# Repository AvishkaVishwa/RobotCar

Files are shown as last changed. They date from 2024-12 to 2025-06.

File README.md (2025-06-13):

# 🤖 Sumo Robot – ESP32 Upgrade Edition

> ⚡ A complete redesign and performance upgrade of my original ESP32-based 2-wheel robot — now featuring 4-wheel differential drive, dual motor drivers, enhanced sensing, and a **custom-designed 2-layer PCB** for clean, robust competition performance.

---
## 🏅 Awards & Achievements

> 🥈 **2nd Place – University Robotics Competition**  
> My previous 2-wheel ESP32-based robot won **2nd place** in a university competition.  
> 🎯 **Challenge Objective:** Remove the maximum number of boxes from a designated area as fast as possible.  
> 💡 The robot autonomously navigated, detected, and pushed objects while avoiding boundaries.  
>
> This new 4-wheel version builds on that success with:
> - A custom PCB for higher stability and motor control
> - Dual-mode (Autonomous + BLE Manual) operation
> - Improved PD-based line tracking and obstacle avoidance
> - Real-time scanning with servo-driven sensors

## 🔄 Evolution of the Project

| Original Prototype | 🚀 **Upgraded Version** |
|---|---|
| ESP32 on protoboard | ESP32 DevKit (38-pin) on custom 2-layer PCB |
| 2-wheel drive with single TB6612FNG  | 4-wheel drive using dual TB6612FNG drivers |
| Breadboard wiring | Professionally routed and labeled PCB in KiCad |
| 1 ultrasonic + 2 IR sensors | 2 ultrasonic + 3 IR sensors |
| Basic C firmware | Modular, RTOS-based firmware with **ESP-IDF** |

### 🔧 The Current design 

| Old Design |
|------------|
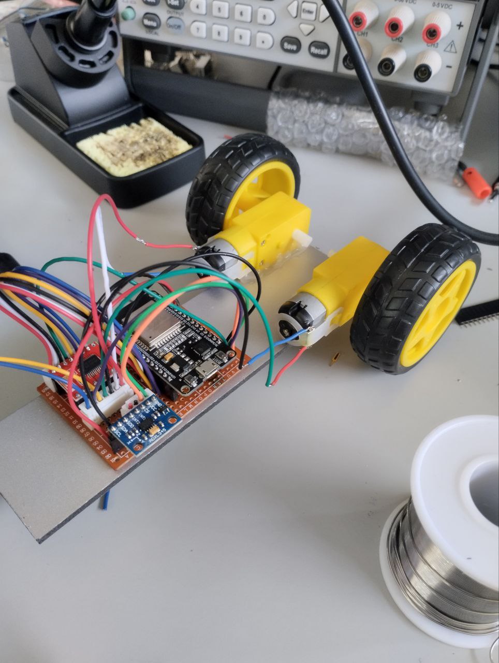
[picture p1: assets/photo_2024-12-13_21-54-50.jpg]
 
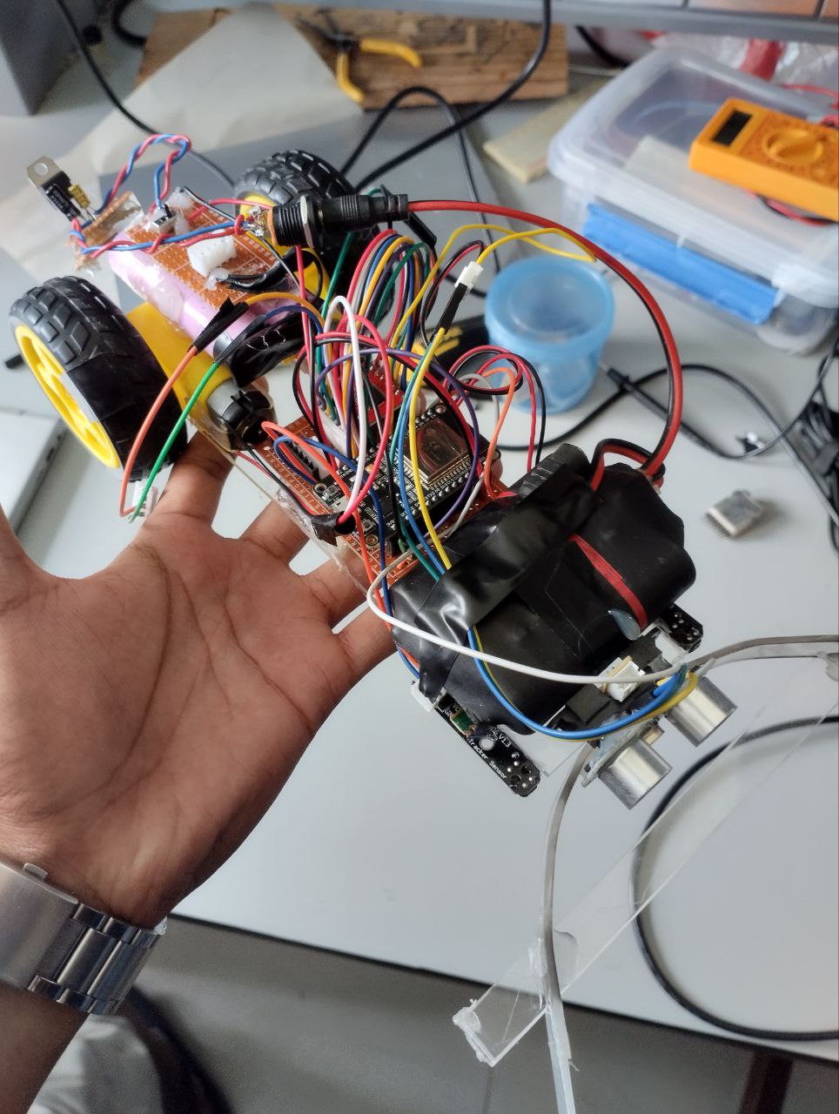
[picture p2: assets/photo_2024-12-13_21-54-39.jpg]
   

---

## ⚙ Hardware Overview

### 📍 ESP32 GPIO Mapping

| Feature | GPIOs | Description |
|---|---|---|
| **Motor Driver 1**  | AIN1: 13, AIN2: 14 | Left Front Motor Direction |
| | BIN1: 12, BIN2: 27 | Left Rear Motor Direction |
| | PWMA: 26, PWMB: 25 | Speed Control (PWM) |
| **Motor Driver 2**  | AIN1: 33, AIN2: 32 | Right Front Motor Direction |
| | BIN1: 19, BIN2: 18 | Right Rear Motor Direction |
| | PWMA: 23, PWMB: 22 | Speed Control (PWM) |
| **STBY Pin** | 15 | Keep HIGH to enable motors |
| **IR Sensors** | 34, 35, 39 | Left, Center, Right (input only) |
| **Ultrasonic** | TRIG1: 5, ECHO1: 36 | Front sensor |
| | TRIG2: 4, ECHO2: 21 | Side sensor |
| **Servos** | SERVO1: 2, SERVO2: 17 | Optional (PWM outputs) |

---

## 📐 PCB Design (KiCad)

This upgrade features a fully custom 2-layer PCB:
- Dual motor driver breakout with decoupling capacitors
- LM2596 buck converter (12V to 5V)
- Pull-up/pull-down resistors for boot-safe ESP32 pins
- Clear silk labels for servo, IR, ultrasonic, and power pins

### PCB Gallery

#### 📘 Schematic View
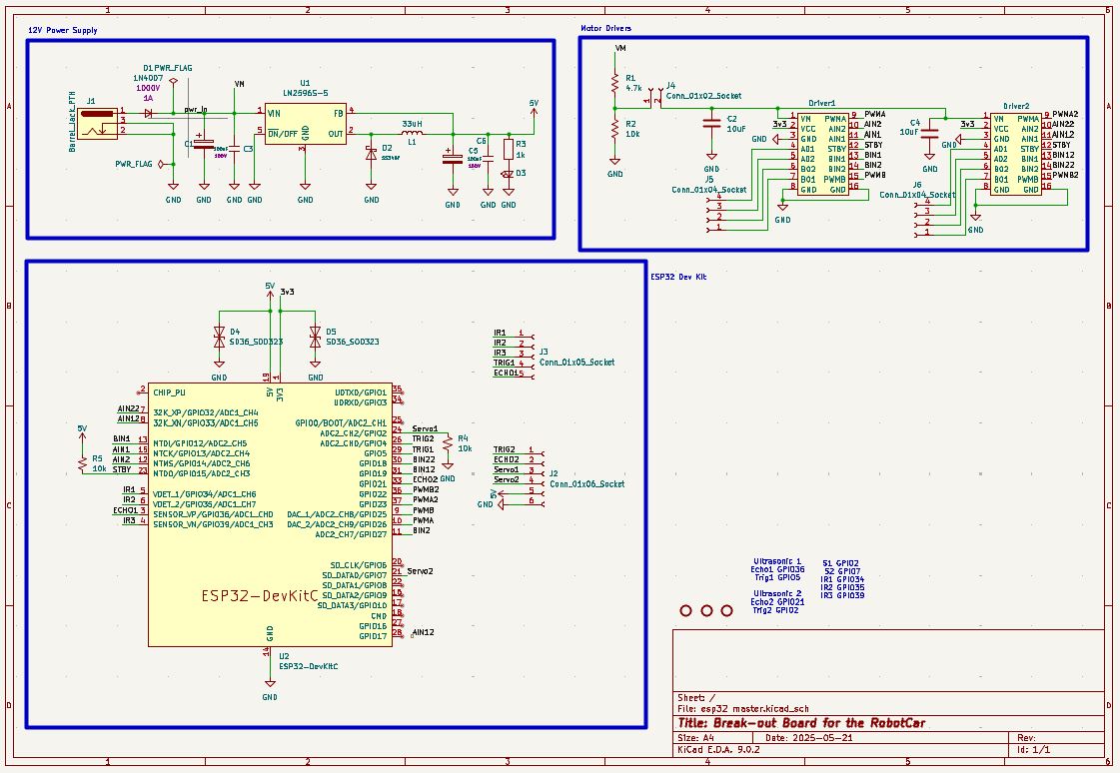
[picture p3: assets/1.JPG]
Schematic


#### 🧵 Routed View
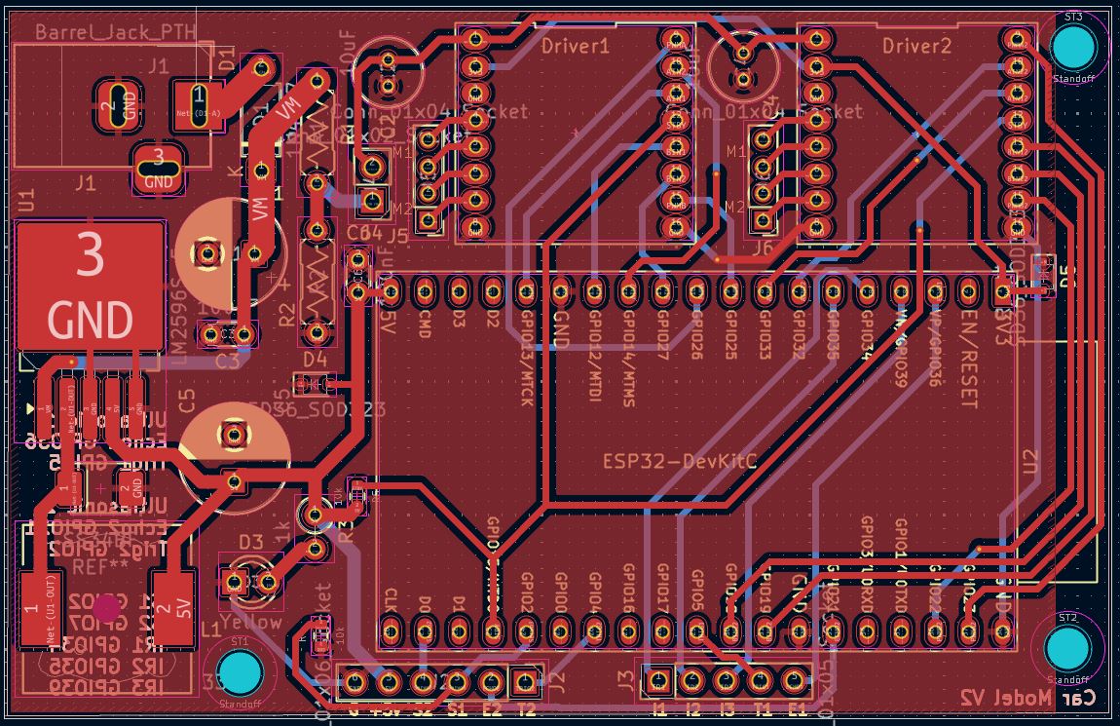
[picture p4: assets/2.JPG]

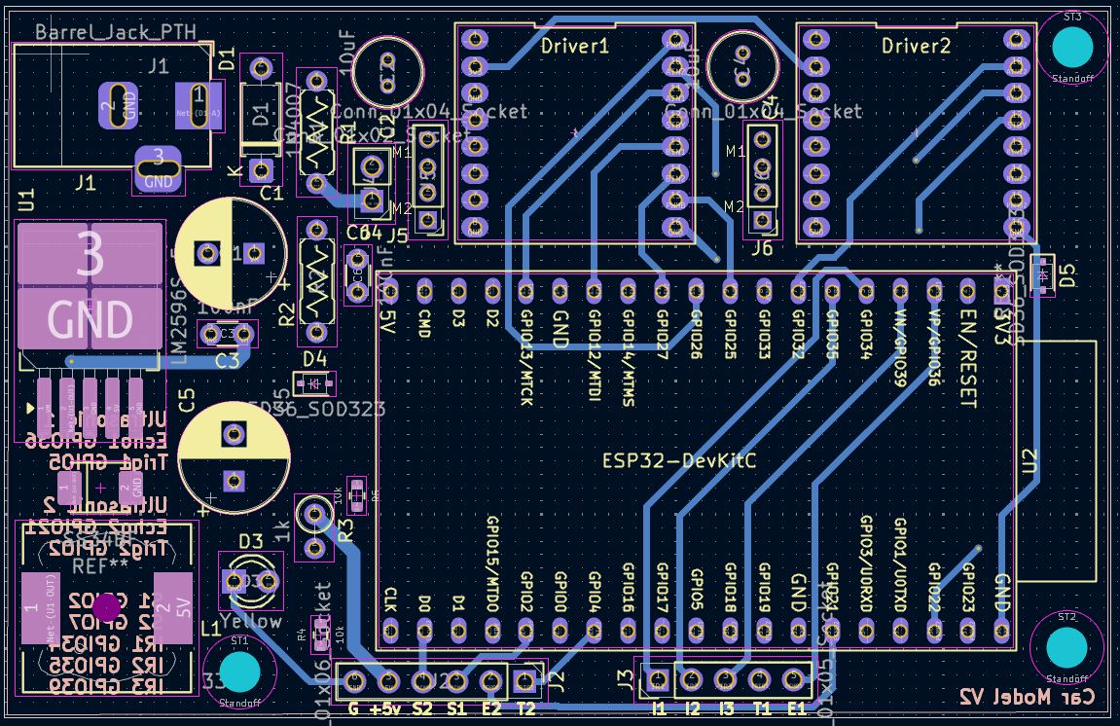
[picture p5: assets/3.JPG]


#### 📐 2D Top View
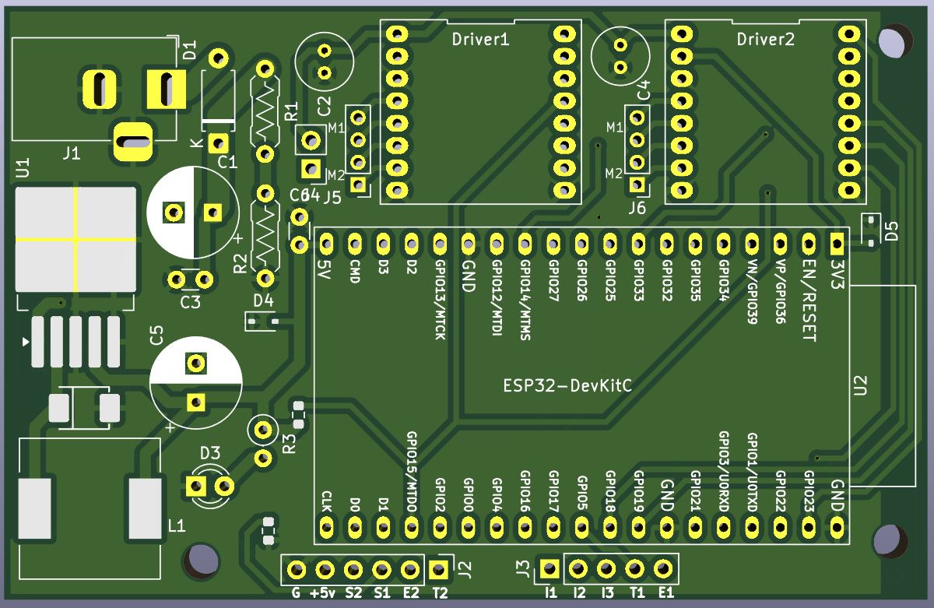
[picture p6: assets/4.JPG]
Top Layout


#### 🧱 3D Render
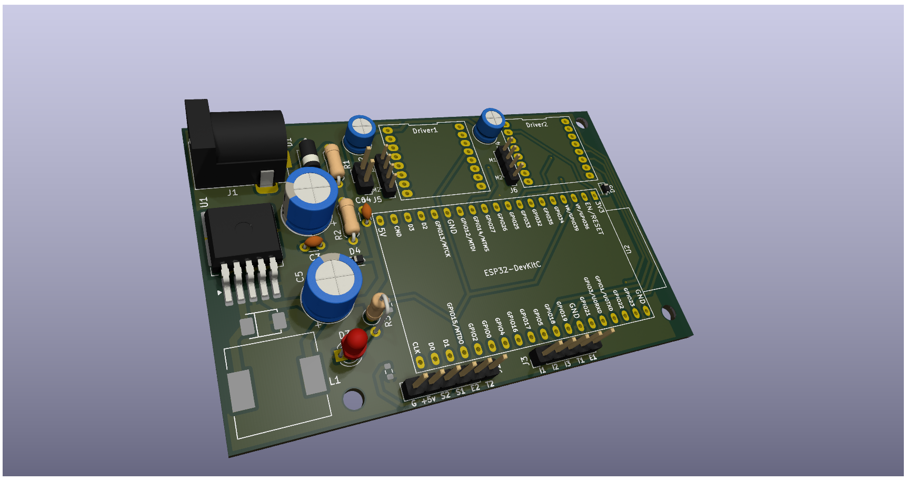
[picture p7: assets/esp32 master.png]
3D View


---

## ⚙ Software Architecture

Built using **ESP-IDF + FreeRTOS**, the firmware is modular and real-time.

| Module | Function |
|---|---|
| `main.c` | Set motor direction and PWM speed |
| | Read ultrasonic and IR sensor values |
| | Control servo angles (expandable feature) |
| | Main loop with attack, avoid, search routines |

---

## 🔧 Setup & Flashing

### Prerequisites
- ESP-IDF environment
- ESP32 DevKit (38-pin)
- 12V battery + USB cable

### Flash Instructions

git clone https://github.com/AvishkaVishwa/RobotCar.git
cd robot-project
idf.py build
idf.py -p /dev/ttyUSB0 flash
idf.py monitor

---

## 📹 Videos & Demos

> 🎥 Want to see it in action?
> I’ve recorded videos of both the prototype and the upgraded robot performing edge detection, object pushing, and spiral search.

📌  <video src ="https://github.com/user-attachments/assets/8567fc42-a18b-4fbb-b69a-60d1c5493e56"></video>

📌 Here Is a test of the car with New PCB, I m still doing some modifications to this....😁 And i'm controlling the car with Bluetooth using the mobile phone.
    <video src ="https://github.com/user-attachments/assets/c9dc8e6a-7c8a-46cb-9330-15c2b81f15a4"></video>
---

## 📚 What This Project Shows

* Embedded firmware development with **ESP-IDF**
* **Custom PCB design** (routing, power, protection, labeling)
* Real-time autonomous behavior
* Motor control using **PWM & H-bridges**
* Sensor fusion: ultrasonic + IR edge detection
* Full-stack development from electronics to software

---

## 🤝 Contributions Welcome

Feel free to fork or suggest ideas such as:

* PID control integration
* Remote control override via WiFi
* OLED display for system status

---
---
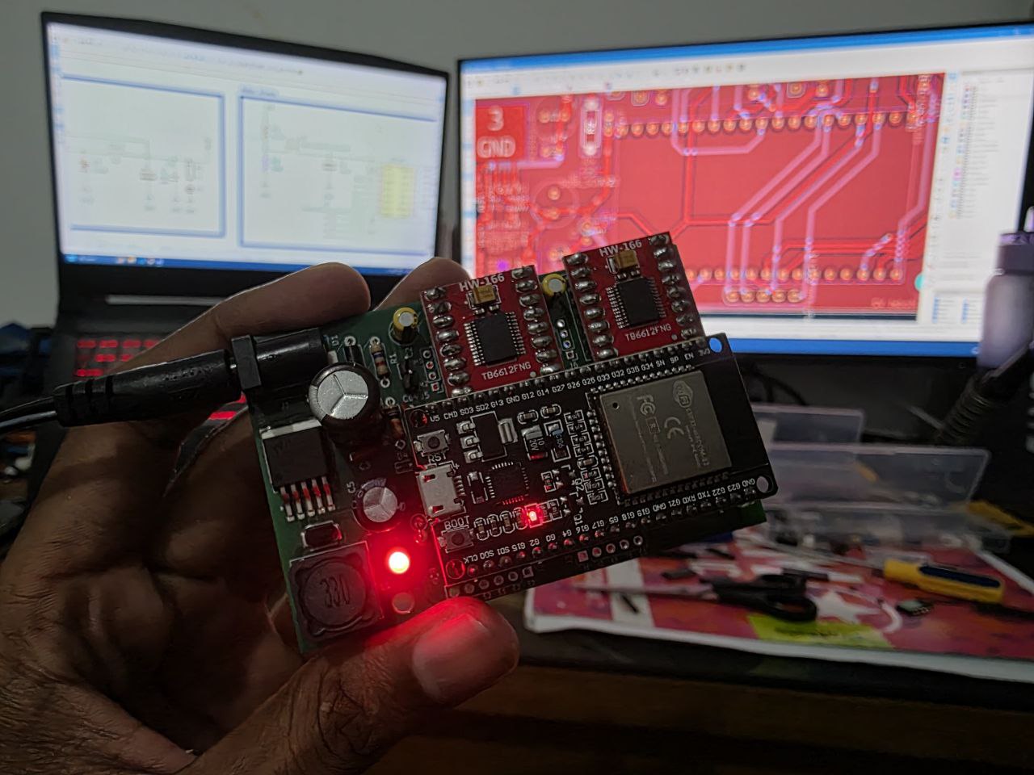
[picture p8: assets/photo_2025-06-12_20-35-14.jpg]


## 🎉 Special Thanks to PCBWay

<p align="center">
  <a href="https://www.pcbway.com/" target="_blank">
    PCBWay
  </a>
</p>

I would like to give a huge shoutout and sincere thanks to **[PCBWay](https://www.pcbway.com/)** for sponsoring the PCB fabrication of this project!

The **build quality, silkscreen clarity, via precision, and copper finish** exceeded expectations. PCBWay’s service was fast, professional, and extremely helpful throughout the production process.

This project wouldn’t have been possible without their generous support. If you’re looking to manufacture professional-grade PCBs at an affordable price, I highly recommend checking them out.

🔗 [Visit PCBWay →](https://www.pcbway.com/)

---

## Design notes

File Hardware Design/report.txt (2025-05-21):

Plotted to 'D:\RobotCar\Hardware Design\Breakout_Board\esp32 master-F_Cu.gbr'.
Plotted to 'D:\RobotCar\Hardware Design\Breakout_Board\esp32 master-B_Cu.gbr'.
Plotted to 'D:\RobotCar\Hardware Design\Breakout_Board\esp32 master-F_Paste.gbr'.
Plotted to 'D:\RobotCar\Hardware Design\Breakout_Board\esp32 master-B_Paste.gbr'.
Plotted to 'D:\RobotCar\Hardware Design\Breakout_Board\esp32 master-F_Silkscreen.gbr'.
Plotted to 'D:\RobotCar\Hardware Design\Breakout_Board\esp32 master-B_Silkscreen.gbr'.
Plotted to 'D:\RobotCar\Hardware Design\Breakout_Board\esp32 master-F_Mask.gbr'.
Plotted to 'D:\RobotCar\Hardware Design\Breakout_Board\esp32 master-B_Mask.gbr'.
Plotted to 'D:\RobotCar\Hardware Design\Breakout_Board\esp32 master-Edge_Cuts.gbr'.
Created Gerber job file 'D:\RobotCar\Hardware Design\Breakout_Board\esp32 master-job.gbrjob'.
Info: Done.
Info: Done.

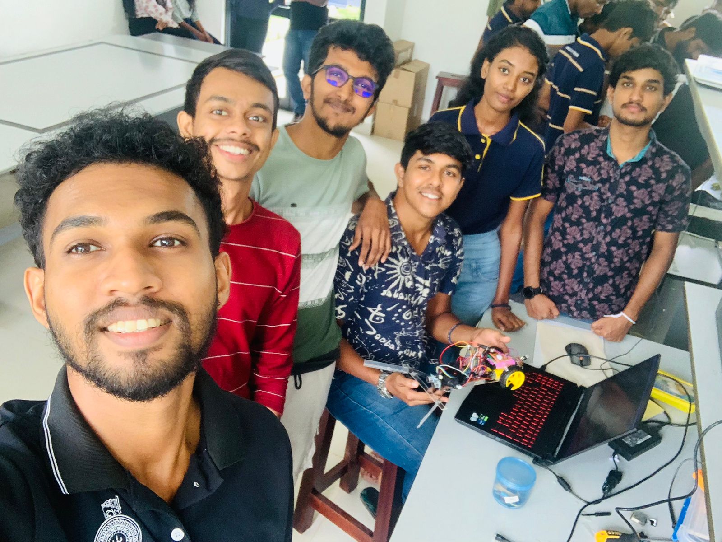
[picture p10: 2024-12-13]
assets/2024-12-13 at 6.29.29 PM (1).jpeg

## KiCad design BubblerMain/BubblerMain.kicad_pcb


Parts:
C13: 0.1uF; C_1206_3216Metric_Pad1.33x1.80mm_HandSolder
C19: 1000uF; CP_Elec_10x10
J2, J3, J4, J5: Conn_01x03_Pin; JST_XH_B3B-XH-AM_1x03_P2.50mm_Vertical
R9, R10, R11, R12: 330; R_1206_3216Metric_Pad1.30x1.75mm_HandSolder
U1: 74AHCT125; SOIC-14_3.9x8.7mm_P1.27mm; LCSC C2675672

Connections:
+5V: C13.1, C19.1, J2.3, J3.3, J4.3, J5.3, U1.14 (VCC); also elsewhere on the board
GND1: C13.2, C19.2, J2.1, J3.1, J4.1, J5.1, U1.1, U1.4, U1.7 (GND), U1.10, U1.13; also elsewhere on the board
LED1 Signal: U1.2; also elsewhere on the board
LED2 Signal: U1.5; also elsewhere on the board
LED3 Signal: U1.9; also elsewhere on the board
LED4 Signal: U1.12; also elsewhere on the board
unnamed: J2.2, R9.1
unnamed: J3.2, R10.1
unnamed: J4.2, R11.1
unnamed: J5.2, R12.1
unnamed: R9.2, U1.3
unnamed: R10.2, U1.6
unnamed: R11.2, U1.8
unnamed: R12.2, U1.11


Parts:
5V2: TestPoint; TestPoint_Pad_2.0x2.0mm
C1: 220uf; CP_Elec_10x10
C2, C3: 10uf; C_1206_3216Metric_Pad1.33x1.80mm_HandSolder
C4: 0.1uF; C_1210_3225Metric_Pad1.33x2.70mm_HandSolder
C5, C6: 22uF; C_1210_3225Metric_Pad1.33x2.70mm_HandSolder
C7: 0.1uF; C_1206_3216Metric_Pad1.33x1.80mm_HandSolder
D1: SMAJ13A; D_SMA
F1: Polyfuse; Fuse_1812_4532Metric
GND1: TestPoint; TestPoint_Pad_2.0x2.0mm
J1: Conn_01x04_Pin; JST_XH_B2B-XH-AM_1x02_P2.50mm_Vertical
L1: 3.3uH; IND_SPM6530T-3R3M; PARTREV N/A; LCSC C76856
Q1: DMP3013SFV; Diodes_PowerDI3333-8; LCSC C264098
R1, R2: 100k; R_1206_3216Metric_Pad1.30x1.75mm_HandSolder
R5: 54.9k; R_1206_3216Metric_Pad1.30x1.75mm_HandSolder
R6: 10k; R_1206_3216Metric_Pad1.30x1.75mm_HandSolder
U9: TPS565201DDCR; SOT95P280X110-6N; LCSC C327676

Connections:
+5V: 5V2.1, C5.1, C6.1, L1.2, R5.1; also elsewhere on the board
/Power Block/BAT+: F1.2, J1.1
/Power Block/Fuse-Pol: F1.1, Q1.5 (D)
GND1: C1.2, C2.2, C3.2, C5.2, C6.2, C7.2, D1.1 (A1), GND1.1, J1.2, R1.2, R6.2, U9.1 (GND); also elsewhere on the board
Motor Power: C1.1, C2.1, C3.1, C7.1, D1.2 (A2), Q1.1 (S), Q1.2 (S), Q1.3 (S), R2.1, U9.3 (VIN); also elsewhere on the board
unnamed: Q1.4 (G), R1.1
unnamed: R2.2, U9.5 (EN)
unnamed: C4.1, L1.1, U9.2 (SW)
unnamed: C4.2, U9.6 (VBST)
unnamed: R5.2, R6.1, U9.4 (VFB)

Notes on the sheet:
Output Filter
Input Filter
Spike Protection
Reverse Polarity Protection


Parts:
3.3V1, 5V1: LED; LED_1206_3216Metric_Pad1.42x1.75mm_HandSolder
3v3: TestPoint; TestPoint_Pad_2.0x2.0mm
C8, C21: 1uF; C_1206_3216Metric_Pad1.33x1.80mm_HandSolder
C9, C22: 22uF; C_1210_3225Metric_Pad1.33x2.70mm_HandSolder
C20: 0.1uF; C_1206_3216Metric_Pad1.33x1.80mm_HandSolder
D2, D3: SS14; D_SMA
FB1: 600; L_1206_3216Metric
J8: USB_C_Receptacle; USB_C_Receptacle_HCTL_HC-TYPE-C-16P-01A
J9: Conn_01x08_Pin; PinHeader_1x08_P2.54mm_Vertical
J12: Conn_01x08_Pin; PinHeader_1x04_P2.54mm_Vertical
MOTOR1: LED; LED_1206_3216Metric_Pad1.42x1.75mm_HandSolder
R16, R17: 5.1k; R_1206_3216Metric_Pad1.30x1.75mm_HandSolder
R18, R19: 10k; R_1206_3216Metric_Pad1.30x1.75mm_HandSolder
R20, R22: 1.5k; R_1206_3216Metric_Pad1.30x1.75mm_HandSolder
R21, R23, R26: 680; R_1206_3216Metric_Pad1.30x1.75mm_HandSolder
SW1, SW2: SW_Push; SW_SPST_PTS645Sx43SMTR92
SW3: LED; LED_1206_3216Metric_Pad1.42x1.75mm_HandSolder
U4: ESP32-S3-WROOM-1; ESP32-S3-WROOM-2; LCSC C2913198
U5: AP2112K-3.3; SOT-23-5; LCSC C23380830
U6: USBLC6-2SC6; SOT-23-6; LCSC C2827654
USB1: LED; LED_1206_3216Metric_Pad1.42x1.75mm_HandSolder

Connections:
+3V3: 3v3.1, C20.1, C22.1, J12.3, R18.1, R19.1, R21.1, U4.2 (3V3), U5.5 (VOUT); also elsewhere on the board
+5V: FB1.1, J12.4; also elsewhere on the board
/ESP32/A6: J8.A6 (D+), J8.B6 (D+), U6.4 (I/O2)
/ESP32/A7: J8.A7 (D-), J8.B7 (D-), U6.6 (I/O1)
/ESP32/GPIO8: J9.1, U4.12 (IO8)
/ESP32/GPIO9: J9.2, U4.17 (IO9)
/ESP32/GPIO10: J9.3, U4.18 (IO10)
/ESP32/GPIO11: J9.4, U4.19 (IO11)
/ESP32/GPIO12: J9.5, U4.20 (IO12)
/ESP32/GPIO13: J9.6, U4.21 (IO13)
/ESP32/GPIO14: J9.7, U4.22 (IO14)
/ESP32/GPIO21: J9.8, U4.23 (IO21)
/ESP32/SW_LED: R23.1, U4.25 (IO48)
/ESP32/VBUS: D2.2 (A), J8.A4 (VBUS), J8.A9 (VBUS), J8.B4 (VBUS), J8.B9 (VBUS), R22.1, U6.5 (VBUS)
GND1: 3.3V1.1 (K), 5V1.1 (K), C8.2, C9.2, C20.2, C21.2, C22.2, J8.A1 (GND), J8.A12 (GND), J8.B1 (GND), J8.B12 (GND), J12.1, MOTOR1.1 (K), R16.2, R17.2, SW1.1, SW2.2, SW3.1 (K), U4.1 (GND), U4.40 (GND), U4.41 (GND), U5.2 (GND), U6.2 (GND), USB1.1 (K); also elsewhere on the board
I2S_SCK: U4.9 (IO16); also elsewhere on the board
I2S_SD: U4.11 (IO18); also elsewhere on the board
I2S_WS: U4.10 (IO17); also elsewhere on the board
LED1 Signal: U4.4 (IO4); also elsewhere on the board
LED2 Signal: U4.5 (IO5); also elsewhere on the board
LED3 Signal: U4.6 (IO6); also elsewhere on the board
LED4 Signal: U4.7 (IO7); also elsewhere on the board
Motor Power: J12.2; also elsewhere on the board
Motor Signal: R26.1, U4.8 (IO15); also elsewhere on the board
unnamed 26: 3.3V1.2 (A), R21.2; also elsewhere on the board
unnamed 27: 5V1.2 (A), R20.2; also elsewhere on the board
unnamed: C8.1, C9.1, D2.1 (K), D3.1 (K), R20.1, U5.1 (VIN), U5.3 (EN)
unnamed: D3.2 (A), FB1.2
unnamed: MOTOR1.2 (A), R26.2
unnamed 45: R23.2, SW3.2 (A); also elsewhere on the board
unnamed: C21.1, R18.2, SW1.2, U4.3 (EN)
unnamed: R19.2, SW2.1, U4.27 (IO0)
unnamed: U4.14 (USB_D+/IO20), U6.3 (I/O2)
unnamed: U4.13 (USB_D-/IO19), U6.1 (I/O1)
unnamed 57: R22.2, USB1.2 (A); also elsewhere on the board
RS485_DE: U4.35 (MTMS/IO42); also elsewhere on the board
RS485_RX: U4.38 (IO2); also elsewhere on the board
RS485_TX: U4.39 (IO1); also elsewhere on the board

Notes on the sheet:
Expansion Header for future use


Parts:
C8, C21: 1uF
C20: 0.1uF
C22: 22uF
D2: SS14
D4, D5, D6, D7: LED
J8: USB_C_Receptacle
R16, R17: 5.1k
R18, R19: 10k
R20, R22: 1.5k
R21, R23: 680
SW1, SW2: SW_Push
U4: ESP32-S3-WROOM-1; ESP32-S3-WROOM-2
U5: AP2112K-3.3; SOT-23-5
U6: USBLC6-2SC6; SOT-23-6

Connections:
+3V3: C20.1, C22.1, R18.1, R19.1, R21.1, U4.2 (3V3), U5.5 (VOUT); also elsewhere on the board
/ESP32/A6: J8.A6 (D+), J8.B6 (D+), U6.4 (I/O2)
/ESP32/A7: J8.A7 (D-), J8.B7 (D-), U6.6 (I/O1)
/ESP32/GPIO8: U4.12 (IO8); also elsewhere on the board
/ESP32/GPIO9: U4.17 (IO9); also elsewhere on the board
/ESP32/GPIO10: U4.18 (IO10); also elsewhere on the board
/ESP32/GPIO11: U4.19 (IO11); also elsewhere on the board
/ESP32/GPIO12: U4.20 (IO12); also elsewhere on the board
/ESP32/GPIO13: U4.21 (IO13); also elsewhere on the board
/ESP32/GPIO14: U4.22 (IO14); also elsewhere on the board
/ESP32/GPIO21: U4.23 (IO21); also elsewhere on the board
/ESP32/SW_LED: R23.1, U4.25 (IO48)
/ESP32/VBUS: D2.2 (A), J8.A4 (VBUS), J8.A9 (VBUS), J8.B4 (VBUS), J8.B9 (VBUS), R22.1, U6.5 (VBUS)
GND1: C8.2, C20.2, C21.2, C22.2, D4.1 (K), D5.1 (K), D6.1 (K), D7.1 (K), J8.A1 (GND), J8.A12 (GND), J8.B1 (GND), J8.B12 (GND), R16.2, R17.2, SW1.1, SW2.2, U4.1 (GND), U4.40 (GND), U4.41 (GND), U5.2 (GND), U6.2 (GND); also elsewhere on the board
I2S_SCK: U4.9 (IO16); also elsewhere on the board
I2S_SD: U4.11 (IO18); also elsewhere on the board
I2S_WS: U4.10 (IO17); also elsewhere on the board
LED1 Signal: U4.4 (IO4); also elsewhere on the board
LED2 Signal: U4.5 (IO5); also elsewhere on the board
LED3 Signal: U4.6 (IO6); also elsewhere on the board
LED4 Signal: U4.7 (IO7); also elsewhere on the board
Motor Signal: U4.8 (IO15); also elsewhere on the board
unnamed 26: D5.2 (A), R21.2; also elsewhere on the board
unnamed 27: D4.2 (A), R20.2; also elsewhere on the board
unnamed 28: C8.1, D2.1 (K), R20.1, U5.1 (VIN), U5.3 (EN); also elsewhere on the board
unnamed 45: D7.2 (A), R23.2; also elsewhere on the board
unnamed: C21.1, R18.2, SW1.2, U4.3 (EN)
unnamed: R19.2, SW2.1, U4.27 (IO0)
unnamed: U4.14 (USB_D+/IO20), U6.3 (I/O2)
unnamed: U4.13 (USB_D-/IO19), U6.1 (I/O1)
unnamed 57: D6.2 (A), R22.2; also elsewhere on the board
RS485_DE: U4.35 (MTMS/IO42); also elsewhere on the board
RS485_RX: U4.38 (IO2); also elsewhere on the board
RS485_TX: U4.39 (IO1); also elsewhere on the board


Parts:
C14, C15: 10uF 25v; C_1206_3216Metric_Pad1.33x1.80mm_HandSolder
C16: 0.1uF; C_1206_3216Metric_Pad1.33x1.80mm_HandSolder
C17, C18: 22uF; C_1210_3225Metric_Pad1.33x2.70mm_HandSolder
J6, J7: Conn_01x02_Pin; JST_XH_B2B-XH-AM_1x02_P2.50mm_Vertical
L2: 3.3uH; IND_SPM6530T-3R3M; PARTREV N/A; LCSC C76856
R13: 35.7k; R_1206_3216Metric_Pad1.30x1.75mm_HandSolder
R14: 10k; R_1206_3216Metric_Pad1.30x1.75mm_HandSolder
R15: 100k; R_1206_3216Metric_Pad1.30x1.75mm_HandSolder
U3: TPS563201DDCR; TSOT-23-6_HandSoldering; PARTREV December 2015; LCSC C116592

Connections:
GND1: C14.2, C15.2, C17.2, C18.2, J6.1, J7.1, R14.2, R15.2, U3.1 (GND); also elsewhere on the board
Motor Power: C14.1, C15.1, U3.3 (VIN); also elsewhere on the board
Motor Signal: R15.1, U3.5 (EN); also elsewhere on the board
unnamed: C17.1, C18.1, J6.2, J7.2, L2.2, R13.1
unnamed: C16.1, L2.1, U3.2 (SW)
unnamed: C16.2, U3.6 (VBST)
unnamed: R13.2, R14.1, U3.4 (VFB)


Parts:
C23, C24: 0.1uF; C_1206_3216Metric_Pad1.33x1.80mm_HandSolder
C25: 4.7uF; C_1206_3216Metric_Pad1.33x1.80mm_HandSolder
J10: Conn_01x04_Pin; JST_XH_B2B-XH-AM_1x02_P2.50mm_Vertical
J11: Conn_01x08_Pin; JST_XH_B8B-XH-AM_1x08_P2.50mm_Vertical
R24, R29: 100k; R_1206_3216Metric_Pad1.30x1.75mm_HandSolder
R25: 120; R_1206_3216Metric_Pad1.30x1.75mm_HandSolder
R27, R28: 33; R_1206_3216Metric_Pad1.30x1.75mm_HandSolder
U7: THVD1400D; SOIC-8_3.9x4.9mm_P1.27mm; LCSC C3235232
U8: SM712; SOT23-WIDE; LCSC C502564

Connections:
+3V3: C23.1, C24.1, C25.1, J11.1, U7.8 (VCC); also elsewhere on the board
GND1: C23.2, C24.2, C25.2, J11.2, J11.4, J11.6, J11.8, R24.2, R29.2, U7.5 (GND), U8.3; also elsewhere on the board
I2S_SCK: R27.2; also elsewhere on the board
I2S_SD: J11.7, R29.1; also elsewhere on the board
I2S_WS: R28.2; also elsewhere on the board
unnamed: J10.1, R25.2, U7.7 (B), U8.1
unnamed: J10.2, R25.1, U7.6 (A), U8.2
unnamed: J11.3, R27.1
unnamed: J11.5, R28.1
RS485_DE: R24.1, U7.2 (~RE), U7.3 (DE); also elsewhere on the board
RS485_RX: U7.1 (RO); also elsewhere on the board
RS485_TX: U7.4 (DI); also elsewhere on the board

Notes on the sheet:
RS485 Transceiver
INMP441 Module Header
INMP441 Module will be on an 8-10 inch lead from the PCB Connected with CAT5 twisted pair. Ground/Signal for each twisted pair.

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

Board: 4 copper layers, 72.0 x 66.0 mm, 85 parts (0 on the bottom side), 63 nets.

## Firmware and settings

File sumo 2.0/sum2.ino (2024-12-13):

// Motor Control Pins for your robot
#define STBY_PIN 33
#define AIN1_PIN 25
#define AIN2_PIN 26
#define PWMA_PIN 27
#define BIN1_PIN 14
#define BIN2_PIN 13
#define PWMB_PIN 12

// Ultrasonic Sensor Pins for your robot
#define TRIG_PIN 18  // Trigger pin
#define ECHO_PIN 32  // Echo pin

// Sensor Pins for your robot
const int leftIRPin = 35;     // Left line detection IR sensor
const int rightIRPin = 34;    // Right line detection IR sensor

// Constants
const int LINE_THRESHOLD = 500;  // Adjust based on your IR sensor readings
const int DISTANCE_THRESHOLD = 40;  // Adjust based on your ultrasonic sensor readings (in cm)
const int PUSH_SPEED = 255;      // Maximum speed for pushing
const int SEARCH_SPEED = 200;    // Speed while searching
const int BACKUP_TIME = 700;     // Time to back up when hitting line

// Spiral search parameters
unsigned long lastDirectionChange = 0;
unsigned long spiralDuration = 100;  // Initial duration for each spiral segment
const unsigned long SPIRAL_INCREMENT = 200;  // How much to increase the duration each spiral
int currentSpiral = 0;  // Keep track of spiral iterations

void setup() {
  Serial.begin(115200);

  // Set motor control pins as outputs
  pinMode(AIN1_PIN, OUTPUT);
  pinMode(AIN2_PIN, OUTPUT);
  pinMode(PWMA_PIN, OUTPUT);
  pinMode(BIN1_PIN, OUTPUT);
  pinMode(BIN2_PIN, OUTPUT);
  pinMode(PWMB_PIN, OUTPUT);
  pinMode(STBY_PIN, OUTPUT);

  // Enable the motor driver
  digitalWrite(STBY_PIN, HIGH);

  // Sensor pins setup
  pinMode(TRIG_PIN, OUTPUT);
  pinMode(ECHO_PIN, INPUT);
  pinMode(leftIRPin, INPUT);
  pinMode(rightIRPin, INPUT);

  delay(5000); // Initial delay as per sumo rules
  lastDirectionChange = millis();  // Initialize the timer
}

long measureDistance() {
  digitalWrite(TRIG_PIN, LOW);
  delayMicroseconds(2);
  digitalWrite(TRIG_PIN, HIGH);
  delayMicroseconds(10);
  digitalWrite(TRIG_PIN, LOW);
  long duration = pulseIn(ECHO_PIN, HIGH);
  long distance = duration * 0.034 / 2; // Convert to centimeters
  return distance;
}

void loop() {
  // Read sensor values
  long frontDistance = measureDistance();
  int leftValue = analogRead(leftIRPin);
  int rightValue = analogRead(rightIRPin);

  // Reset spiral search if box is found
  if (frontDistance < DISTANCE_THRESHOLD) {
    currentSpiral = 0;
    spiralDuration = 500;
  }

  // Debug output
  Serial.print("Distance: ");
  Serial.print(frontDistance);
  Serial.print(" Left: ");
  Serial.print(leftValue);
  Serial.print(" Right: ");
  Serial.println(rightValue);

  // Check for line detection first
  if (leftValue < LINE_THRESHOLD || rightValue < LINE_THRESHOLD) {
    // Hit the line - back up and turn
    Stop();
    Serial.println("Action: Hit line, backing up and turning");
    BACKWARD(PUSH_SPEED);
    delay(BACKUP_TIME);
    Stop();
    // Turn about 90 degrees
    ROTATE(SEARCH_SPEED);
    delay(500);
    return;
  }

  // Box detection and removal logic
  if (frontDistance < DISTANCE_THRESHOLD) {  // Ultrasonic sensor: closer distance means smaller value
    // Box detected - charge at full speed
    Serial.println("Action: Box detected, moving forward to push");
    FORWARD(PUSH_SPEED);
    // Keep pushing until we hit a line
    while (frontDistance < DISTANCE_THRESHOLD) {
      frontDistance = measureDistance();
      leftValue = analogRead(leftIRPin);
      rightValue = analogRead(rightIRPin);

      // Check if we've hit a line
      if (leftValue < LINE_THRESHOLD || rightValue < LINE_THRESHOLD) {
        // Back up and search for new box
        Stop();
        Serial.println("Action: Hit line while pushing, backing up");
        BACKWARD(PUSH_SPEED);
        delay(BACKUP_TIME);
        break;
      }
      delay(10);
    }
  } else {
    // No box detected - search in spiral pattern
    unsigned long currentTime = millis();
    
    if (currentTime - lastDirectionChange >= spiralDuration) {
      currentSpiral++;
      lastDirectionChange = currentTime;
      
      if (currentSpiral % 2 == 0) {
        // Increase spiral duration every two segments
        spiralDuration += SPIRAL_INCREMENT;
      }
      
      // Alternate between moving forward and rotating
      if (currentSpiral % 2 == 0) {
        Serial.println("Action: Spiral search - moving forward");
        FORWARD(SEARCH_SPEED);
      } else {
        Serial.println("Action: Spiral search - rotating");
        ROTATE(SEARCH_SPEED);
      }
    }
  }
}

// Motor control functions
void BACKWARD(int Speed) {
  digitalWrite(AIN1_PIN, LOW);
  digitalWrite(AIN2_PIN, HIGH);
  analogWrite(PWMA_PIN, Speed);

  digitalWrite(BIN1_PIN, LOW);
  digitalWrite(BIN2_PIN, HIGH);
  analogWrite(PWMB_PIN, Speed);
}

void FORWARD(int Speed) {
  digitalWrite(AIN1_PIN, HIGH);
  digitalWrite(AIN2_PIN, LOW);
  analogWrite(PWMA_PIN, Speed);

  digitalWrite(BIN1_PIN, HIGH);
  digitalWrite(BIN2_PIN, LOW);
  analogWrite(PWMB_PIN, Speed);
}

void ROTATE(int Speed) {
  digitalWrite(AIN1_PIN, HIGH);
  digitalWrite(AIN2_PIN, LOW);
  analogWrite(PWMA_PIN, Speed);

  digitalWrite(BIN1_PIN, LOW);
  digitalWrite(BIN2_PIN, HIGH);
  analogWrite(PWMB_PIN, Speed);
}

void Stop() {
  digitalWrite(AIN1_PIN, LOW);
  digitalWrite(AIN2_PIN, LOW);
  analogWrite(PWMA_PIN, 0);

  digitalWrite(BIN1_PIN, LOW);
  digitalWrite(BIN2_PIN, LOW);
  analogWrite(PWMB_PIN, 0);
}

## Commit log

2024-12-13 Add motor control and sensor integration for robot navigation
2024-12-17 Enhance robot navigation with improved sensor integration and motor control
2025-05-20 Refactor code structure for improved readability and maintainability
    [esp32 master-B_Cu.gbr, esp32 master-B_Mask.gbr, esp32 master-B_Paste.gbr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]
2025-05-21 Revise README.md for clarity and detail in ESP32 upgrade, enhancing hardware overview and software architecture sections
2025-05-21 Update README.md to reflect current design changes and replace schematic image with updated version
2025-05-21 Update README.md to replace schematic images with new versions for improved clarity
2025-05-21 Update README.md to replace PCB top layout image with a new version for improved clarity
2025-05-21 Update drill files and job configuration for esp32 breakout board
    - Updated creation dates in NPTH and PTH drill files to 2025-05-21.
    - Adjusted coordinates in PTH drill file for improved accuracy.
    - Modified creation date in job configuration file to match the latest updates.
    - Added a new image to the README for better documentation.
    - Generated a report file detailing the plotted Gerber files for the breakout board.
    [esp32 master-B_Cu.gbr, esp32 master-B_Mask.gbr, esp32 master-B_Paste.gbr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]
2025-06-13 Add initial KiCad project files for car design
    [car.kicad_pcb, car.kicad_sch]
